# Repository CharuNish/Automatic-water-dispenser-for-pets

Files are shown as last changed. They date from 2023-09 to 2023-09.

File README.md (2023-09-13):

# Automatic-water-dispenser-for-pets
In the modern world, pet owners often face challenges in providing constant care and attention to 
their beloved companions due to their busy lifestyles. A significant issue arises when it comes to 
ensuring a continuous supply of clean water for pets, particularly during prolonged absences. To 
address this concern, we present a groundbreaking solution: an Automatic Water Dispenser for 
Pets. This innovative device is designed to detect the presence of pets and dispense water on 
demand, ensuring they have access to fresh water whenever they need it. 

## Design Process
### Determining features
To full fill the identified requirements following features were incoparated.
- Automatic detection of the presence of the animal with precision.
- Monitoring water level within the container
- Buzzer Alert System to alert the pet owner.

### Block Diagram
<p align="center">
  
</p>

### Functionality
The functionality process of the product is as follows:
- **Water level sensing:** The water level sensor continuously monitors the water level within the main reservoir. When the water level drops to a low point, the system activates a buzzer, promptly alerting the pet owner to refill the main reservoir, ensuring that the dispenser is always ready to meet the needs of the pets.
- **Dispensing Water:** Upon refilling the main reservoir with sufficient water, the buzzer deactivates, signaling that the dispenser is ready for use. When the ultra-sonic sensor detects the presence of an animal, such as a pet, the system triggers the microcontroller to activate the motor. 
- **Water Pumping:** The motor activates the water pump, facilitating the flow of water to the drinking plate positioned above. Pets can access a steady stream of clean water, promoting their wellbeing and ensuring they have access to fresh water whenever they need it.
- **Intelligent Water Recycling:** As the pet leaves the drinking area, any remaining water on the plate flows back into the dispenser through a filtration process. The filtration system efficiently cleans and purifies the water, removing impurities and contaminants, making it safe for future consumption.
- **Return to Main Reservoir:** Filtered water then returns to the main reservoir, where it is stored and ready for the next use. This process ensures that water is conserved and utilized responsibly, addressing concerns of water wastage and promoting sustainable pet care practices. 

### Component Selection
- **Atmega328P Microcontroller:** The Atmega328P serves as the brain of the system, controlling and coordinating the various components
- **HC-SR04 Ultrasonic Sensor:** The HC-SR04 ultrasonic sensor detects the presence of animals in proximity to the dispenser. The ultrasonic transmitter and receiver detect the presence of an object 2cm to 400cm away. Its ultrasonic transmitter produces 40kHz signal and the receiver collects the reflected signal if the object is within range.
- **SEN18 Water Level Sensor:** This sensor has ten exposed conducting tracks, of which five alternate strips are power tracks and the other five are sensing tracks. When the sensor is submerged in water (vertically), bridges are created between the five pairs of power and sensing tracks due to water’s conductivity. Thus, the sensor works like a variable resistor whose value at the sensing pin changes with the change in water level. The value is high when the water level is high and low when water level is low. The sensor can be powered with 3.3V or 5V on-board DC supply. The SEN18 water level sensor is crucial for monitoring the water level in the main reservoir. It enables the system to detect when the water level is low, triggering an alert for the owner to refill the reservoir.
- **5V Relay Module:** The 5V relay module acts as a switch to control the 12V submersible water pump. It allows the microcontroller to activate and deactivate the pump efficiently, controlling the flow of water to the drinking plate.
- **12V/2A Power Adapter:** The 12V/2A power adapter converts AC 230V to DC 12V and supplies the necessary power to the system, ensuring smooth and reliable operation of all components.
- **12V Submersible Water Pump:** The 12V submersible water pump is responsible for pumping water from the main reservoir to the drinking plate when activated by the microcontroller. Its submersible design ensures efficient water transfer while maintaining a tidy appearance.

### Schematic Design

<p align="center">
  
</p>

### BoM
  
| Component | Quantity |
| --- | ---|
|5V Relay Module  | 1 |
|12V Submergible water pump  | 1 |
|ATMega328P Microcontroller  | 1 |
|HC-SR04 Ultrasonic Sensor | 1 |
|SEN18 Water level sensor |	1 |
|12V Power Adapter | 1 |
|0.1µF Capacitor | 1 |
|0.33µF Capacitor |	1 |
|22pF Capacitor | 2 |
|L7805 Voltage regulator | 1 |
|16MHz Crystal Oscillator  |	1 |
|10kΩ resistor |	1 |
|Buzzer 	| 3 |
|JST Connectors (2port) |	2|
|JST Connectors (3port) |	1|
|JST Connectors (4port) |	1|
|JST Connectors (5port) |	1|

### PCB Design
Printed circuit board was designed with Altium Designer 23.3.1. It was a two-layer design. Manufacturing was done at JLCPCB in China. 

<p align="center">
  
</p>

#### Top Layer
<p align="center">

</p>

#### Bottom Layer
<p align="center">

</p>

### Enclosure Design
Enclosure design was designed with SOLIDWORKS 2020.enclosure consists of plate, sink and container. Plastic is used in the enclosure. 3mmx 5mm screws were used to connect parts. 

<div style="display: flex;">
  
  
</div>

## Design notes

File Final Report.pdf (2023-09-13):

## Department of Electronic and Telecommunication Engineering

## University of Moratuwa

## Semester 4 – Intake 2020

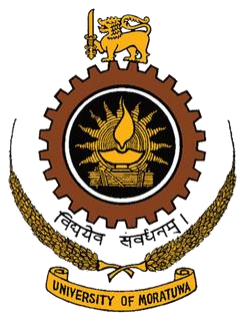
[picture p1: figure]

## Development of an Automatic Water Dispenser for pets

## Final Report

## H.M.C.N.K. Bandara

200063X

This document is submitted as a partial fulfilment of module EN2160 - Electronic Design Realization

July 25, 2023

## Table of Contents

## Abstract

In the modern world, pet owners often face challenges in providing constant care and attention to their beloved companions due to their busy lifestyles. A significant issue arises when it comes to ensuring a continuous supply of clean water for pets, particularly during prolonged absences. To address this concern, we present a groundbreaking solution: an Automatic Water Dispenser for Pets. This innovative device is designed to detect the presence of pets and dispense water on demand, ensuring they have access to fresh water whenever they need it. The dispenser's advanced filtration system guarantees that the water remains clean and safe for consumption, while any unused water is efficiently redirected back to the main reservoir for recycling. Furthermore, the system is equipped with alerts, promptly notifying pet owners to refill the water container when it becomes depleted. Thus, the objective of this report is to present a comprehensive solution that offers long-lasting access to clean water for pets, while promoting energy efficiency, cost-effectiveness, and accessibility to cater to the needs of both individual and institutional pet care scenarios.

## 1. Problem Definition

### 1.1. Introduction to the problem

The significance of pets in people's lives remains undeniably profound, yet the demands of contemporary busy schedules have left pet owners overwhelmed, leading to a concerning neglect of their pets' wellbeing. Furthermore, in a world where individuals often live in solitude, the desire for companionship drives a growing interest in adopting pets. However, potential pet adopters are frequently discouraged by the substantial costs and time commitment required for proper pet care.

In the absence of pet owners for extended periods, the conventional method of providing water through bowls proves inadequate, as pets are left to drink stagnant and potentially contaminated water for days or face dehydration due to insufficient water supply. The challenge extends beyond individual pet owners, with institutions like animal shelters, pet shops, and veterinary clinics struggling to ensure timely access to clean water for many animals in their care.

Though water fountains exist in the market, their reliance on continuous electricity raises concerns about sustainability and affordability. To address these multifaceted challenges, a pressing need arises for an innovative solution capable of providing pets with a constant supply of clean water for extended periods without depleting vital resources or imposing significant financial burdens on pet owners and institutions alike.

### 1.2. Need Analysis

The need analysis for the Automatic Water Dispenser for Pets, based on discussions and interviews with key stakeholders including pet owners, veterinarians, and pet shop owners, revealed the following essential requirements:

- Convenience for Busy Pet Owners: With modern lifestyles becoming increasingly hectic, pet owners are in dire need of a solution that alleviates the burden of constantly providing fresh water to their pets. The Automatic Water Dispenser offers a seamless and automated water supply, catering to the needs of busy pet owners who may be absent for extended periods.
- Enhanced Pet Wellbeing: The wellbeing of pets is a primary concern for all stakeholders. Ensuring access to clean and uncontaminated water is essential for maintaining the health and vitality of pets. The dispenser's filtration system, which purifies and recirculates water, guarantees that pets can always drink safe and fresh water.
- Addressing Loneliness: In an era where individuals often experience loneliness due to living alone, pets serve as valuable companions. The Automatic Water Dispenser supports this aspect by facilitating pet adoption, offering a solution for potential pet owners who seek companionship but are hesitant due to the time and effort required for pet care.

- Efficiency for Institutional Pet Care: Stakeholders involved in managing animal shelters, pet shops, and veterinary clinics face the challenge of providing water to a large number of animals. The Automatic Water Dispenser addresses this need by offering a consistent and efficient water supply system for institutional pet care settings.
- Sustainability and Energy Conservation: In the pursuit of a greener and more sustainable approach, stakeholders expressed the importance of an energy-efficient solution. The dispenser's ability to minimize electricity consumption and conserve water through recycling aligns with this critical need.
- Affordability and Accessibility: Stakeholders emphasized the significance of an affordable solution that is accessible to a wide range of customers. Cost-effective implementation of the Automatic Water Dispenser allows for broader adoption and benefits both individual pet owners and institutional users.
- User-Friendly Interface and Maintenance: A user-friendly design, simple installation, and easy maintenance were identified as essential attributes for the success of the product. Stakeholders highlighted the importance of clear instructions and guides to ensure seamless usage and upkeep of the dispenser.
- Real-Time Alerts and Monitoring: The need for timely alerts to refill the water container when it runs low was emphasized. Real-time monitoring and notifications enable pet owners and institutional caregivers to address water supply needs promptly, ensuring pets' continuous access to water.

In conclusion, the need analysis indicates that the Automatic Water Dispenser for Pets effectively addresses the pressing concerns of key stakeholders. By offering convenience, improved pet wellbeing, and sustainability, the product presents a comprehensive solution that aligns with the interests and requirements of pet owners, veterinarians, and pet shop owners alike.

## 2. Market Goals

- Competitive Pricing and Affordability: Offer competitive price of Rs.20 000 that ensures the product's accessibility to a broad customer base, appealing to both price-conscious individual pet owners and budget-conscious institutional buyers.
- Penetration and Adoption: The primary market goal is to achieve widespread penetration and adoption of the Automatic Water Dispenser in the pet care market, targeting both individual pet owners and institutional customers, such as animal shelters, pet shops, and veterinary clinics.
- Market Leadership: Establish the product as a market leader by offering a superior and innovative solution that outperforms existing water dispensing options, positioning it as the go-to choice for pet owners and caregivers seeking an automated, energy-efficient, and cost-effective solution.
- Brand Awareness and Trust: Build strong brand awareness and trust among potential customers through effective marketing strategies, testimonials, and positive reviews, highlighting the product's benefits and reliability.
- Market Expansion: Explore opportunities for market expansion by targeting new geographical regions and demographics, recognizing the growing global demand for pet care solutions, especially in urban areas with busy pet owners.
- Customer Satisfaction and Retention: Focus on customer satisfaction by continuously improving the product's functionality, durability, and user experience, leading to increased customer retention and loyalty.
- Partnerships and Distribution Channels: Forge strategic partnerships with pet supply stores, veterinarians, and online retailers to expand the product's distribution channels, making it readily available to potential customers.
- Regulatory Compliance: Ensure the product complies with all relevant safety and environmental regulations, obtaining necessary certifications to instill confidence in customers and regulatory bodies.
- Sustainable Growth and Profitability: Achieve sustainable growth and profitability in the market, balancing product quality, cost-effectiveness, and scalability to create a strong foundation for the company's long-term success.

- Customer Education: Emphasize the importance of the Automatic Water Dispenser's features, benefits, and environmental impact through educational content, tutorials, and guides to empower customers to make informed purchasing decisions.

By pursuing these market goals, the Automatic Water Dispenser for Pets aims to become a leading and trusted solution in the pet care industry, meeting the needs of both pet owners and institutional customers while promoting responsible and sustainable pet care practices.

## 3. Design Process

### 3.1. Determining the features

To address the requirements outlined in the need list, the following components and design considerations are proposed:

- Ultra Sonic Sensor: The Automatic Water Dispenser for Pets incorporates an advanced Ultra Sonic Sensor, enabling the product to detect the presence of the animal with precision. This feature directly addresses the need for convenience for busy pet owners, ensuring that water is dispensed only when the pet is present, eliminating unnecessary water wastage and optimizing the dispenser's efficiency.
- Water Level Sensor: With its integrated Water Level Sensor, the dispenser intelligently monitors the water level within the container. This crucial feature fulfills the need for enhanced pet wellbeing, as it prevents pets from drinking contaminated water or facing dehydration by alerting pet owners when the water level is low. Additionally, for institutional settings, the sensor helps manage water supply efficiently, benefiting pet shops, vet clinics, and animal shelters, where the proper care of numerous animals is essential.
- Buzzer Alert System: To meet the requirement of real-time alerts and monitoring, the Automatic Water Dispenser is equipped with a Buzzer Alert System. When the water level reaches a critical point, the buzzer promptly notifies pet owners to refill the container. This not only ensures that pets always have access to fresh water, but also addresses the need for sustainability, as it minimizes water wastage and helps pet owners conserve resources responsibly.

### 3.2. Block Diagram

The proposed block diagram outlines the system’s functionality and critical components.

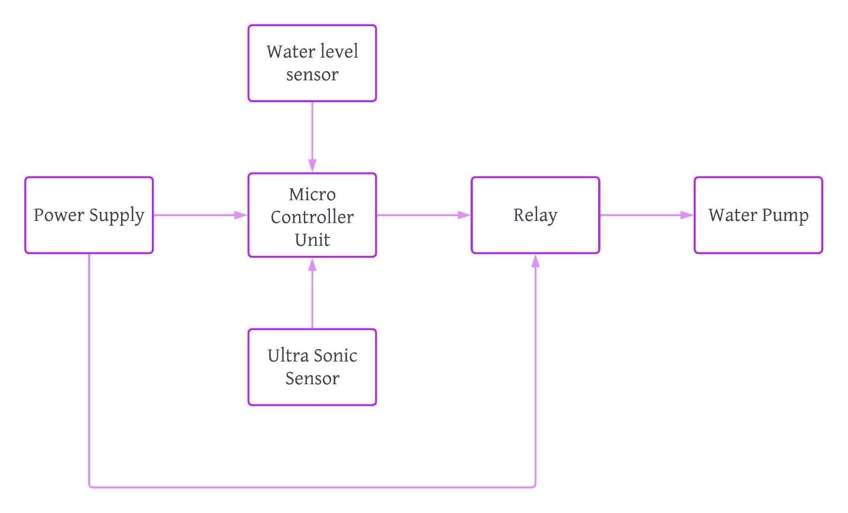
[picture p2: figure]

### 3.3. Functionality

The functionality process of the product is as follows:

- Water Level Sensing:
The water level sensor continuously monitors the water level within the main reservoir. When the water level drops to a low point, the system activates a buzzer, promptly alerting the pet owner to refill the main reservoir, ensuring that the dispenser is always ready to meet the needs of the pets.
- Dispensing Water:
Upon refilling the main reservoir with sufficient water, the buzzer deactivates, signaling that the dispenser is ready for use. When the ultra-sonic sensor detects the presence of an animal, such as a pet, the system triggers the microcontroller to activate the motor.
- Water Pumping:
The motor activates the water pump, facilitating the flow of water to the drinking plate positioned above. Pets can access a steady stream of clean water, promoting their wellbeing and ensuring they have access to fresh water whenever they need it.

- Intelligent Water Recycling:
As the pet leaves the drinking area, any remaining water on the plate flows back into the dispenser through a filtration process. The filtration system efficiently cleans and purifies the water, removing impurities and contaminants, making it safe for future consumption.
- Return to Main Reservoir:
Filtered water then returns to the main reservoir, where it is stored and ready for the next use. This process ensures that water is conserved and utilized responsibly, addressing concerns of water wastage and promoting sustainable pet care practices.

## 4. Implementation

### 4.1. Components Selection

Selected Components for Successful Implementation of the Automatic Water Dispenser for Pets:

1. Atmega328P Microcontroller: The Atmega328P serves as the brain of the system, controlling and coordinating the various components. It is connected to water-level sensor and ultrasonic sensor, which detect water level and pet’s presence near the water bowl, respectively. When ultrasonic sensor detects presence of the pet nearby, it provides a signal to Atmega328P. The Atmega328P program compares the received signal with the programmed value and gives signal to its digital output to operate (energize) relay if the programmed conditions are fulfilled. Otherwise, the relay remains de-energized. Data Sheet (https://www.alldatasheet.com/view.jsp?Searchword=ATMEGA328P&sField=4)
2. HC-SR04 Ultrasonic Sensor: The HC-SR04 ultrasonic sensor detects the presence of animals in proximity to the dispenser. The ultrasonic transmitter and receiver detect the presence of an object 2cm to 400cm away. Its ultrasonic transmitter produces 40kHz signal and the receiver collects the reflected signal if the object is within range. Data Sheet (https://www.electroschematics.com/hc-sr04-datasheet/)
3. SEN18 Water Level Sensor: This sensor has ten exposed conducting tracks, of which five alternate strips are power tracks and the other five are sensing tracks. When the sensor is submerged in water (vertically), bridges are created between the five pairs of power and sensing tracks due to water’s conductivity. Thus, the sensor works like a variable resistor whose value at the sensing pin changes with the change in water level. The value is high when the water level is high and low when water level is low. The sensor can be powered with 3.3V or 5V on-board DC supply. The SEN18 water level sensor is crucial for monitoring the water level in the main reservoir. It enables the system to detect when the water level is low, triggering an alert for the owner to refill the reservoir. User Manual (https://curtocircuito.com.br/datasheet/sensor/nivel_de_agua_analogico.pdf)
4. 5V Relay Module: The 5V relay module acts as a switch to control the 12V submersible water pump. It allows the microcontroller to activate and deactivate the pump efficiently, controlling the flow of water to the drinking plate. Data Sheet (https://components101.com/sites/default/files/component_datasheet/Relay-Module-Datasheet.pdf)

5. 12V/2A Power Adapter: The 12V/2A power adapter converts AC 230V to DC 12V and supplies the necessary power to the system, ensuring smooth and reliable operation of all components. It provides sufficient power for the microcontroller, sensors, relay module, and water pump.
6. 12V Submersible Water Pump: The 12V submersible water pump is responsible for pumping water from the main reservoir to the drinking plate when activated by the microcontroller. Its submersible design ensures efficient water transfer while maintaining a tidy appearance.

By integrating these selected components into the design and implementation of the Automatic Water Dispenser for Pets, the product is equipped with the necessary tools to detect pets' presence, manage water levels, and provide a continuous supply of clean water. The combination of the microcontroller, sensors, relay module, power adapter, and water pump create a comprehensive and efficient system that fulfills the product's intended functionalities and addresses the needs of both individual pet owners and institutional pet care providers.

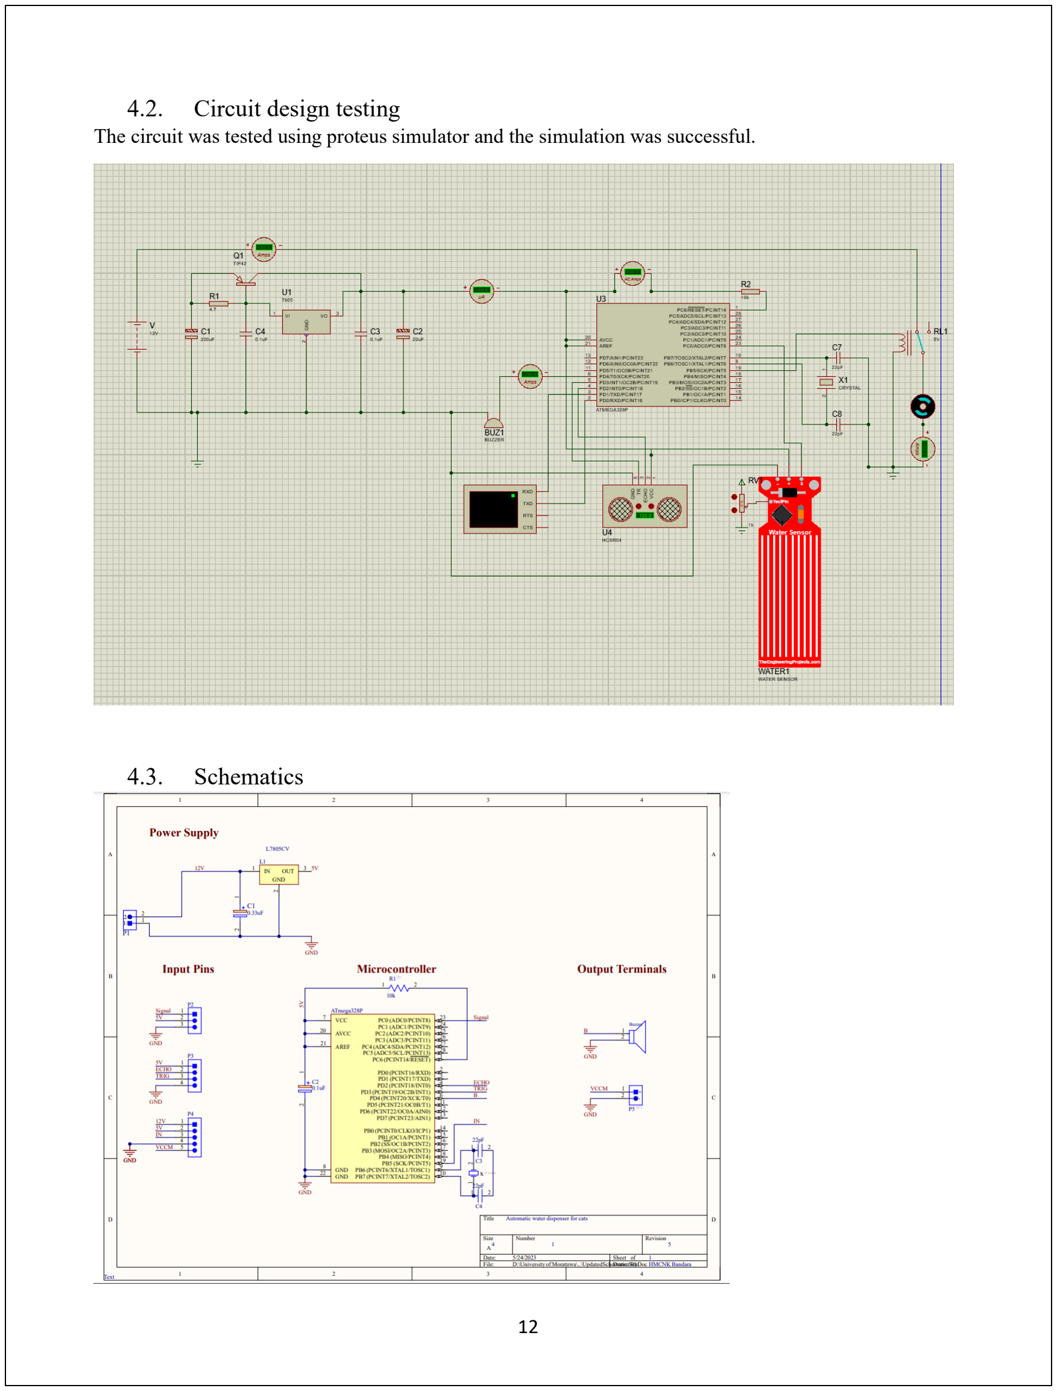
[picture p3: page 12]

### 4.2. Circuit design testing

The circuit was tested using proteus simulator and the simulation was successful.

### 4.3. Schematics

### 4.4. Printed Circuit Board Design

Printed circuit board was designed with Altium Designer 23.3.1. It was a two-layer design. Manufacturing was done at JLCPCB in China. Therefore, online available JLCPCB design rules were imported to Altium Designer.

Refer Appendix I for schematic diagram and layout respectively.

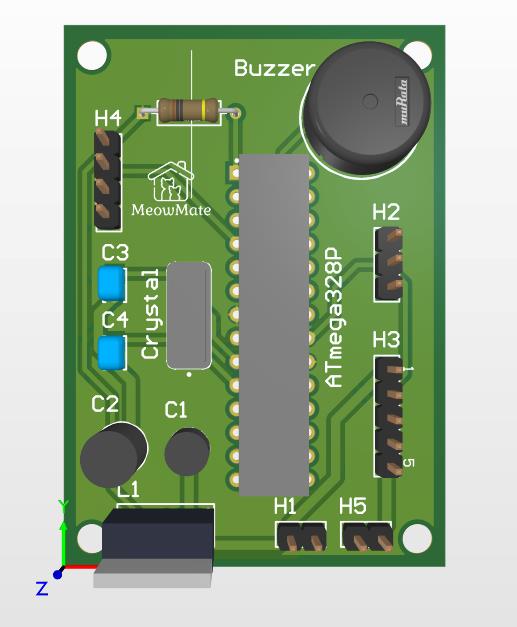
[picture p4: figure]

### 4.5. Enclosure Design

Enclosure design was designed with SOLIDWORKS 2020.enclosure consists of plate, sink and container. Plastic is used in the enclosure. 3mmx 5mm screws were used to connect parts.

### SOLIDWORKS Design

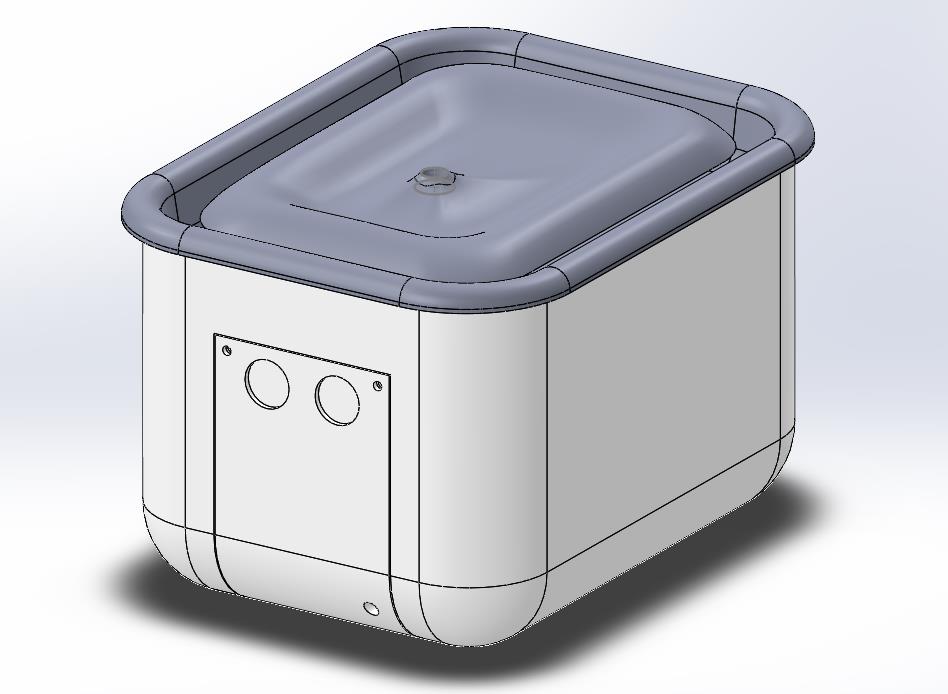
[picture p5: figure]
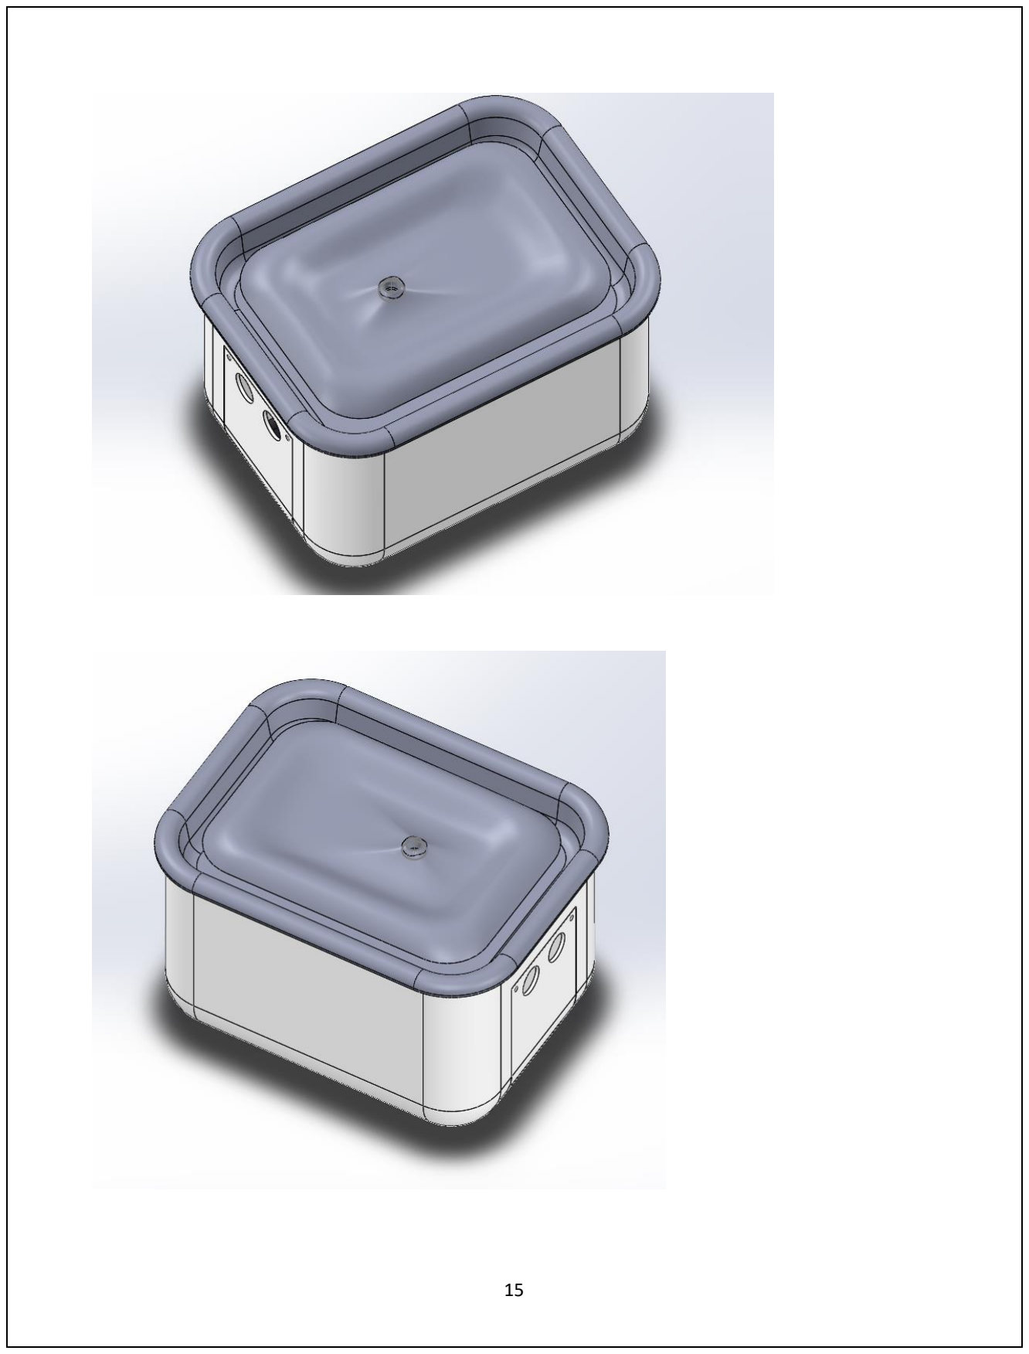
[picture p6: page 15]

## 5. BOM

Description | Quantity
5V Relay Module | 1
12V Submergible water pump | 1
ATMega328P Microcontroller | 1
HC-SR04 Ultrasonic Sensor | 1
SEN18 Water level sensor | 1
12V Power Adapter | 1
0.1µF Capacitor | 1
0.33µF Capacitor | 1
22pF Capacitor | 2
L7805 Voltage regulator | 1
16MHz Crystal Oscillator | 1
10kΩ resistor | 1
Buzzer | 1
JST Connectors (2port) | 2
JST Connectors (3port) | 1
JST Connectors (4port) | 1
JST Connectors (5port) | 1
Wires | 1m
PCB (Manufactured by JLC PCB) | 1
Enclosure | 1

## 6. Software implementation

### Calibration

#define sensorPin A0

int val = 0;

void setup()

{

Serial.begin(9600);

}

void loop() {

int level = readSensor();

delay(1000);

}

int readSensor() {

val = analogRead(sensorPin);

return val;

}

### Dispenser

int Threshold = 650;

#define sensorPin A0

#define echoPin 2

#define trigPin 3

#define Control 13

int val = 0;

long duration;

int distance;

void setup()

{

Serial.begin(9600);

pinMode(trigPin, OUTPUT);

pinMode(echoPin, INPUT);

pinMode(Control, OUTPUT);

digitalWrite(Control, LOW);

}

void loop()

{

digitalWrite(trigPin, LOW);

delayMicroseconds(2);

digitalWrite(trigPin, HIGH);

delayMicroseconds(10);

digitalWrite(trigPin, LOW);

duration = pulseIn(echoPin, HIGH);

distance = duration * 0.034 / 2;

int level = analogRead(A0);

if (distance > 30)

{

digitalWrite(Control,LOW);

}

else

{

if (level > Threshold)

{

digitalWrite(Control, LOW);

}

else

{

digitalWrite(Control, HIGH);

}

delay(100);

}

}

## 7. Future Developments

In the pursuit of future developments for the Automatic Water Dispenser for Pets, the following innovative approaches can be explored:

- Smart Connectivity: Incorporate Wi-Fi or Bluetooth connectivity to allow pet owners to remotely monitor and control the dispenser through a dedicated mobile app. This feature enables real-time alerts, water level monitoring, and convenient dispenser activation, even when the owners are away from home.
- Pet Recognition and Personalization: Implement advanced sensors and machine learning algorithms to recognize and differentiate between multiple pets. This technology would allow for personalized water dispensing settings based on each pet's preferences and needs, ensuring optimal hydration for every individual.
- Enhanced Filtration System: Upgrade the filtration system to include additional stages, such as activated carbon or UV purification, to further enhance water quality. This improvement would effectively remove a broader range of contaminants, ensuring the cleanest and safest drinking water for pets.
- Advanced Water Level Monitoring: Introduce an advanced water level monitoring system that provides historical data and usage patterns. This valuable information can be used to analyze pets' drinking habits, detect any irregularities, and optimize water usage for improved efficiency.
- Variable Reservoir Capacities: Offer a range of main reservoir capacities to cater to the diverse needs of pet owners, accommodating single-pet households as well as multi-pet environments. This flexibility ensures that the dispenser can be tailored to individual requirements.
- Food Dispensing Integration: Explore the possibility of integrating a food dispensing system alongside the water dispenser. This innovation would enable pet owners to automate feeding routines, enhancing convenience and promoting a balanced diet for their pets.
- Medicine Dispensing Capability: Add a system that allows for the precise addition of medicine to the water for individual pets. This feature would aid in administering medications to pets, particularly useful for those with specific health conditions or in need of regular supplements.

By incorporating these innovative approaches into the Automatic Water Dispenser for Pets, the product can truly revolutionize the way pet owners care for their beloved companions. With smart connectivity, personalized pet care, advanced filtration, and additional functionalities like food and medicine dispensing, the dispenser becomes a comprehensive and intelligent solution for pet health and wellbeing.

## 8. Appendix

### Appendix I – PCB

### Schematic

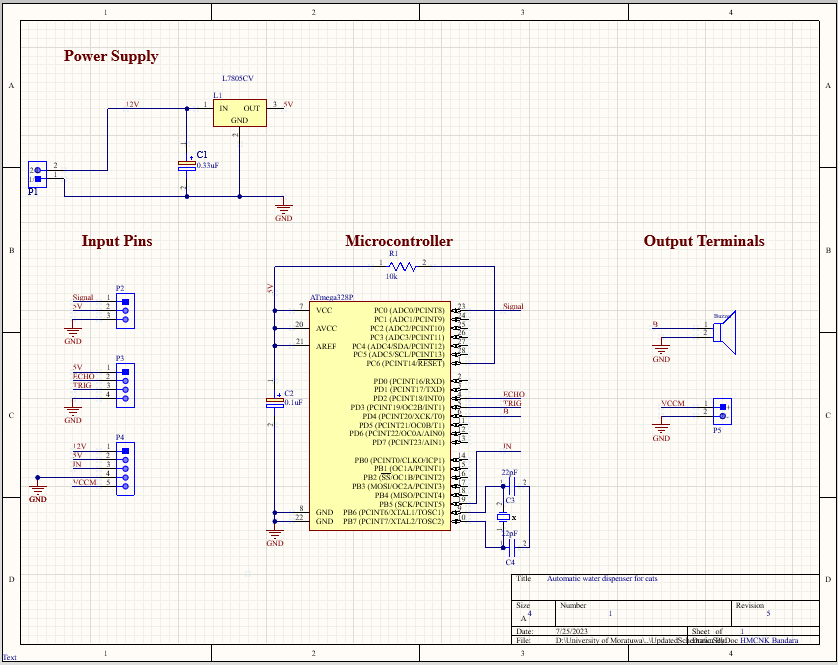
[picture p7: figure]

### 2D - Top Layer

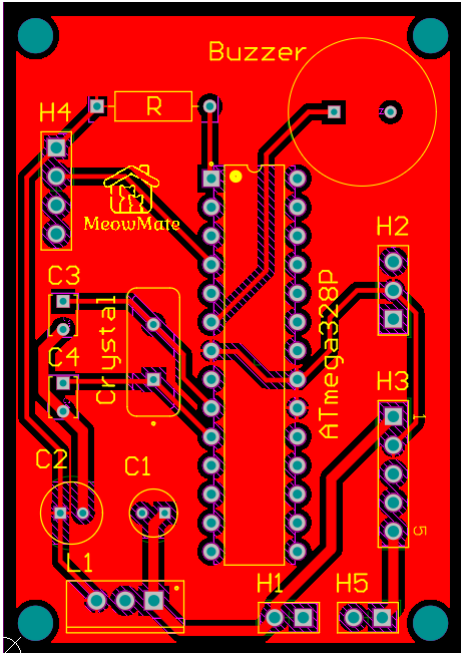
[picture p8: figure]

### 2D - Bottom Layer

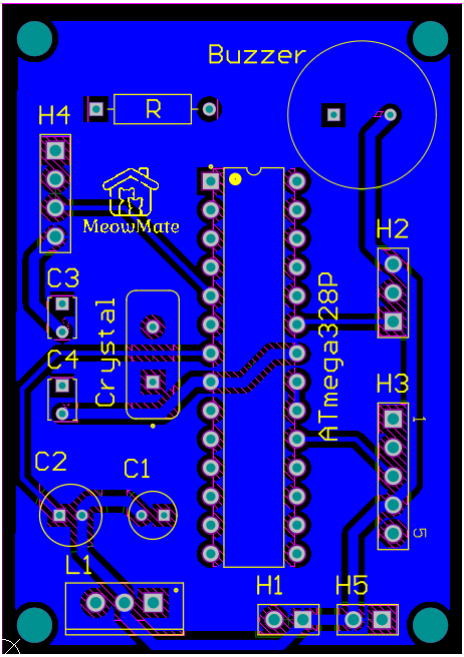
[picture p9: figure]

### Board Planning mode

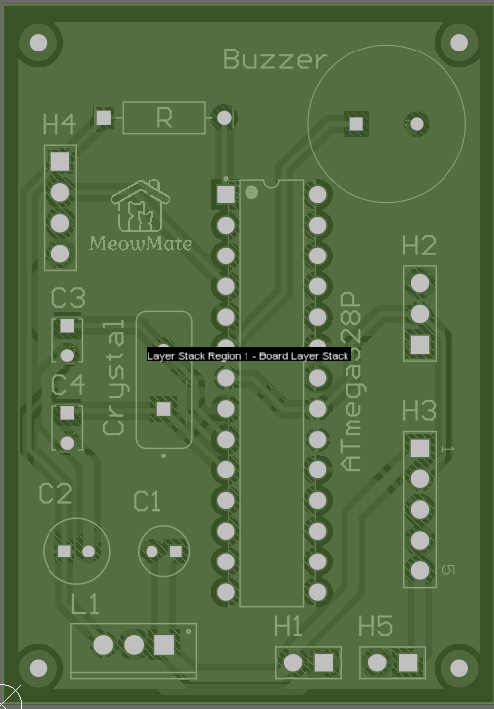
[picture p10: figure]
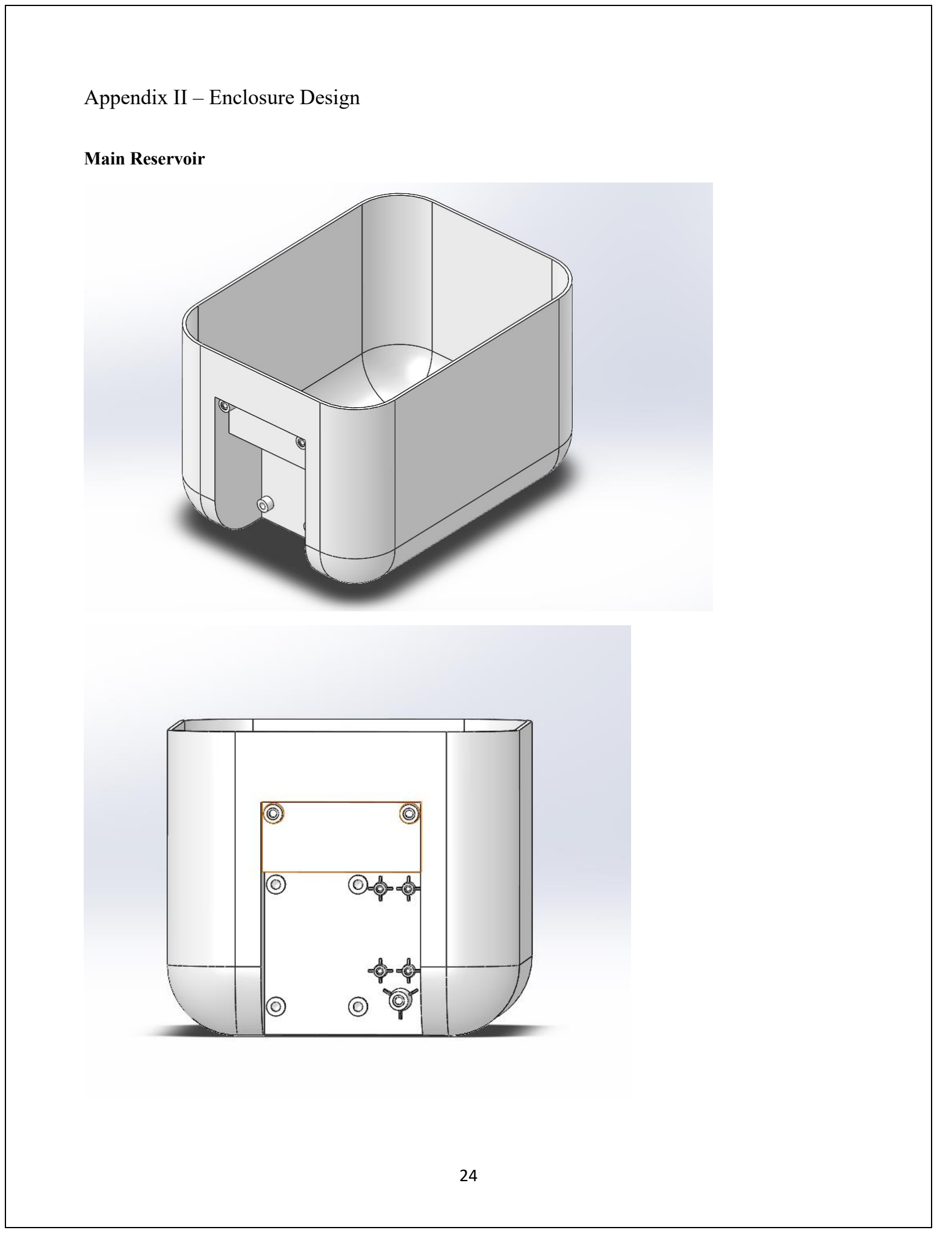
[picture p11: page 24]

### Appendix II – Enclosure Design

Main Reservoir

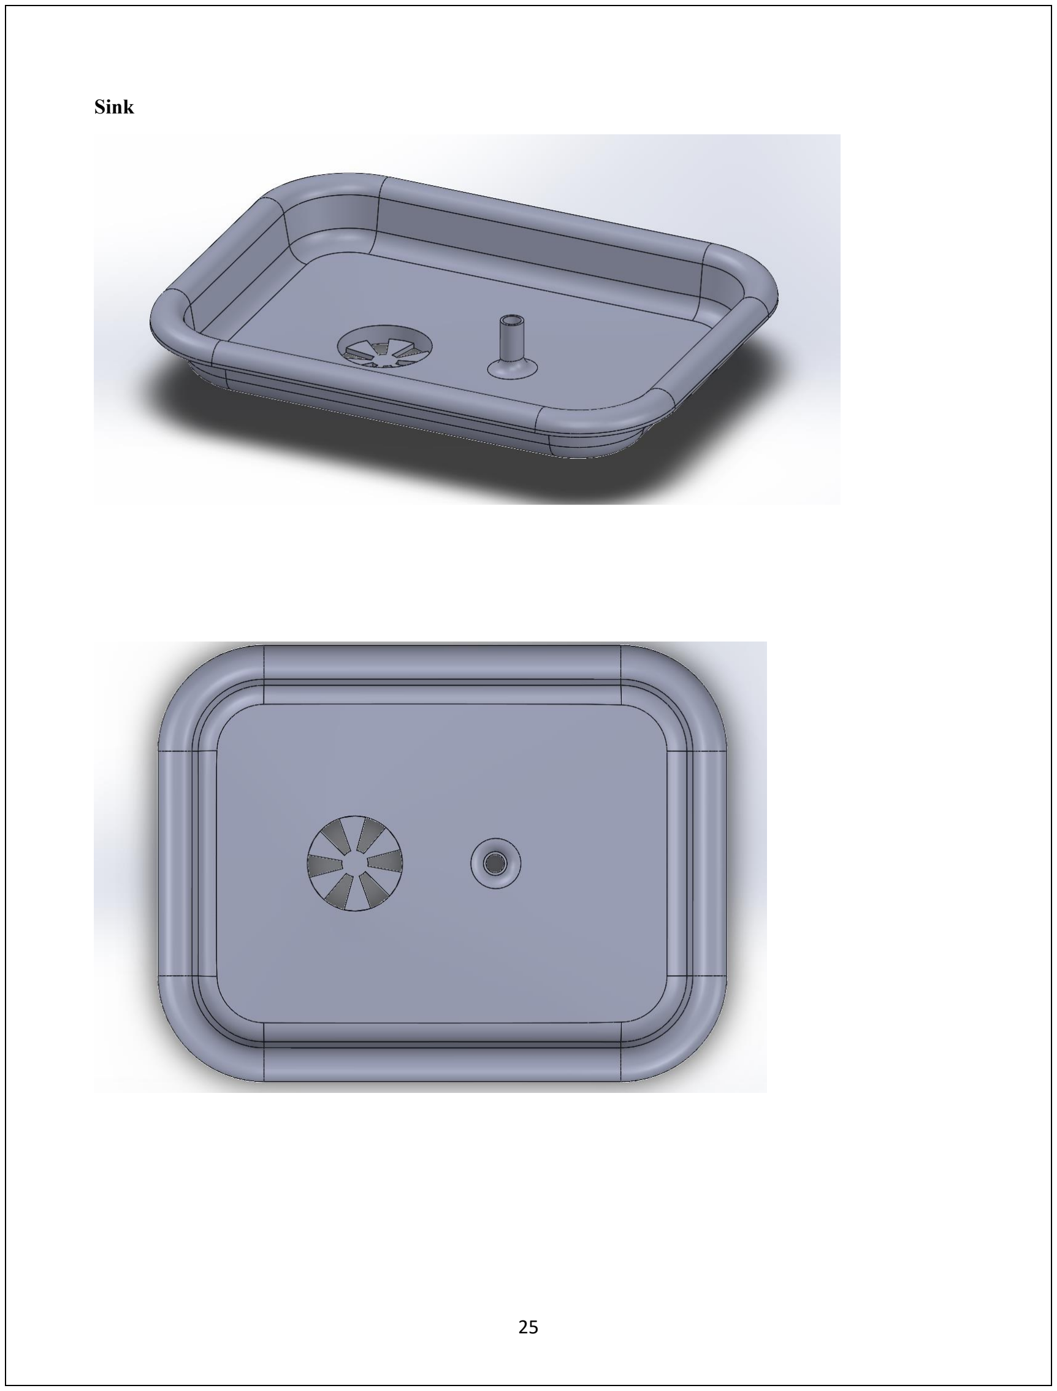
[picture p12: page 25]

Sink

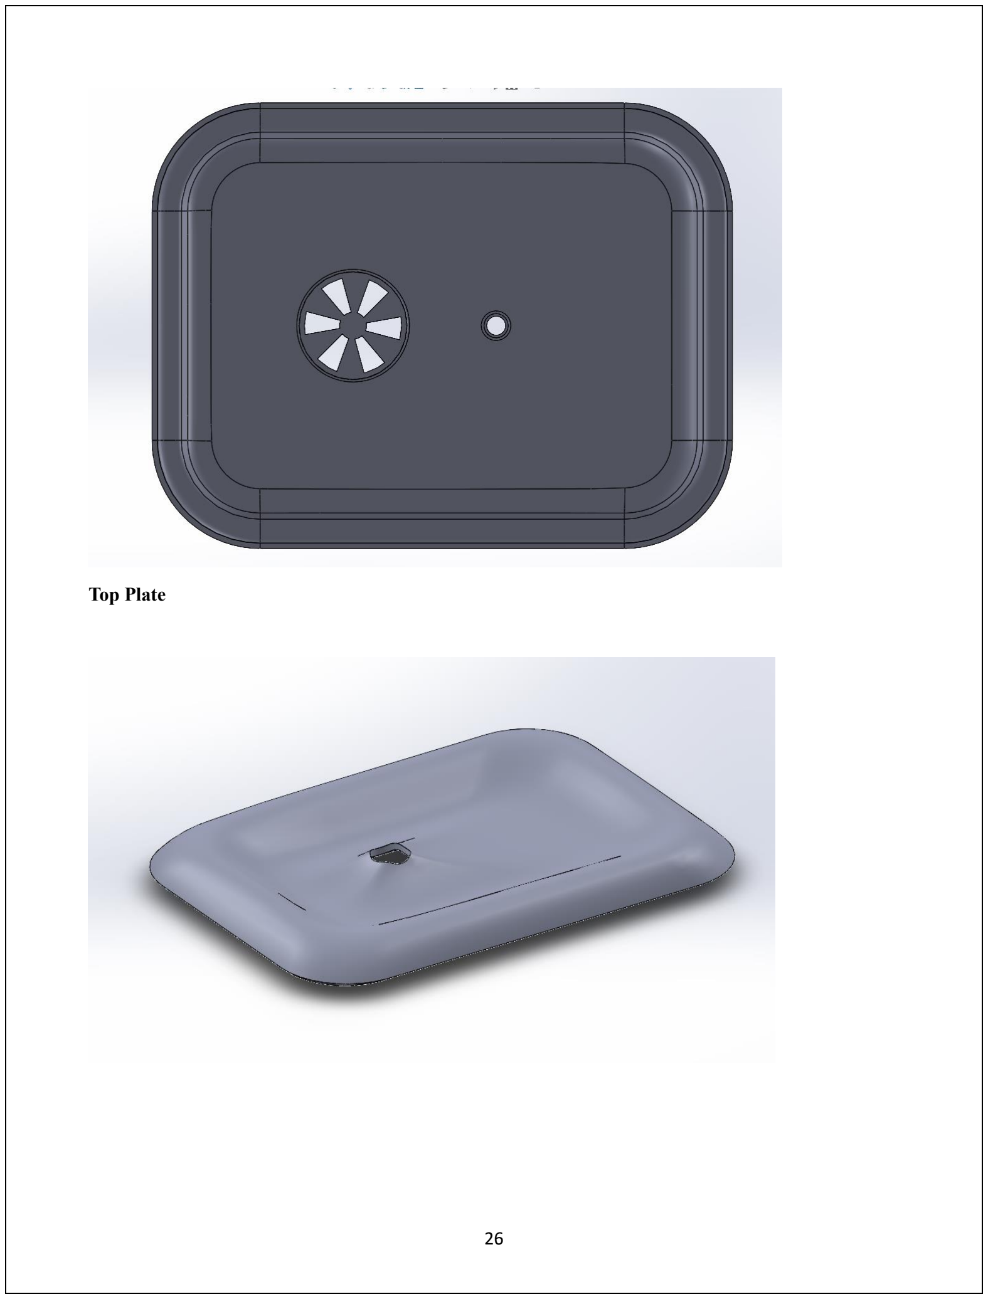
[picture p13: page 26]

Top Plate

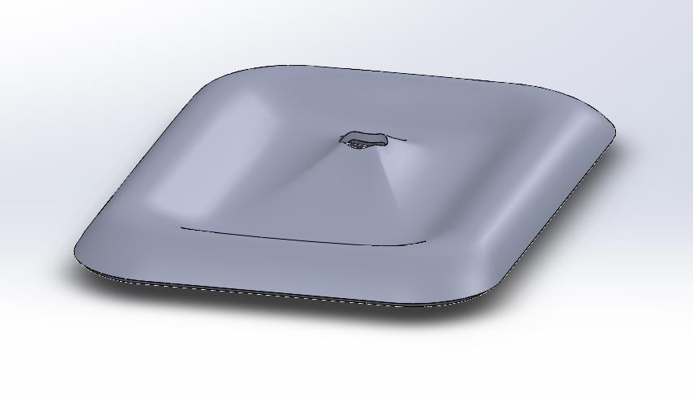
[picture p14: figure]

### Appendix 3 – User Manual

User Manual – Automatic water dispenser for pets

Introduction

Thank you for choosing our Automatic Water Dispenser for Pets. This user manual aims to provide you with all the necessary information to ensure a seamless and safe experience while using our product. The dispenser is designed to provide a constant supply of clean water for your pets, even when you are away, promoting their wellbeing and health.

Product Overview

The Automatic Water Dispenser for Pets is an innovative device that automatically detects your pet's presence and dispenses water on demand. Equipped with an ultra-sonic sensor and water level sensor, the dispenser ensures efficient water usage and filtration for your pet's convenience. The smart design allows for water recycling, making it an energy-efficient and eco-friendly solution.

Key Features

- Ultra-sonic Sensor: Detects your pet's presence, activating the water dispensing mechanism when needed.
- Water Level Sensor: Monitors the water level in the main reservoir and alerts you when it's time to refill.
- Buzzer Alert System: Notifies you when the water level is low and requires refilling.
- Energy-efficient: The dispenser conserves water through intelligent recycling and minimizes electricity consumption.
- Filtration System: Ensures clean and safe water for your pets by removing impurities and contaminants.
- User-friendly Interface: Simple controls make it easy to set up and operate the dispenser.

Safety Precautions

- Use only the provided power adapter and specified accessories to avoid damage or hazards.
- Do not immerse the main unit in water to prevent electrical hazards.
- Regularly check the power cord for signs of damage and ensure its kept away from sharp objects or pet bites.

Assembling

1. Unbox the Automatic Water Dispenser for Pets and ensure all components are included.
2. Attach the water pump securely to the main container's designated compartment.
3. Place the filtration system in the filter compartment in the sink.
4. Connect the power adapter to the dispenser and the electrical outlet.
5. Wait for the buzzer sound to confirm proper setup.

Maintenance

- Regularly check and clean the water pump and filtration system to ensure optimal performance.
- Refill the main reservoir as needed, guided by the water level sensor and buzzer alerts.
- If the dispenser exhibits any unusual behavior or malfunctions, refer to the troubleshooting section of this manual or contact our customer support for assistance.

Troubleshooting

1. Water Dispenser Not Activating
- Check if the power adapter is securely connected to the dispenser and the electrical outlet.
- Ensure that the power switch is turned on.
- Verify that the water level is sufficient for the dispenser to activate.
2. No Water Flowing to the Drinking Plate
- Check if the water pump is securely connected to the dispenser and the power supply.
- Inspect the water pump for any clogs or obstructions that may be blocking the water flow.
- Ensure that the water level is above the minimum requirement for the pump to function properly.
3. Buzzer Continuously Activated
- Check the water level in the main reservoir. Refill the reservoir if the water level is low.
- Inspect the water level sensor for any debris or malfunctions that may be triggering the alert.
- Ensure that the water level sensor is securely connected to the dispenser.
4. Water Leakage from the Dispenser
- Check for any cracks or damage in the dispenser's exterior that may be causing the leakage.
- Verify that all connections, especially those related to the water pump and filtration system, are tightly sealed.
- Ensure that the dispenser is placed on a level surface to prevent water from spilling.
5. Unusual Noises During Operation
- Check for any loose components or parts within the dispenser.
- Inspect the water pump for any foreign objects that may be causing the noise.
- If the noise persists, contact our customer support for further assistance.
6. Inaccurate Sensor Detection
- Clean the sensors and PCB carefully to remove any dirt or debris that might be affecting their functionality.
- Ensure that there are no obstacles or obstructions in the sensor's detection area.
- If the issue persists, consider recalibrating the sensors or contact our customer support for guidance.
7. Dispenser Not Powering On
- Check the power adapter and electrical outlet for any issues. Try using a different outlet.
- If the power adapter appears damaged or faulty, replace it with a compatible one.
- Inspect the power switch and make sure it is functioning correctly.

Safety Information and Warnings

- Do not attempt to disassemble or repair the dispenser yourself. Contact authorized service personnel for any repairs.
- Avoid exposing the dispenser to extreme temperatures or direct sunlight.
- Always unplug the dispenser from the power outlet before cleaning or performing any maintenance.
- If the dispenser or power cord is damaged, discontinue use immediately and seek professional assistance.

We hope this user manual helps you make the most of your Automatic Water Dispenser for Pets. For any further inquiries or assistance, feel free to contact our customer support team.

Note: The contents of this user manual are subject to change without notice due to ongoing product improvements. Please refer to the latest version available on our website for the most up-to-date information.

### Appendix 4 - Maintenance Manual

Maintenance Manual – Automatic water dispenser for pets

Introduction

Welcome to the Maintenance Manual for the Automatic Water Dispenser for Pets. Regular maintenance is essential to ensure the longevity and optimal performance of your product. This manual provides step-by-step instructions for cleaning, troubleshooting, and handling of the dispenser, ensuring a safe and seamless experience for you and your pets.

Maintenance Schedule

Regular inspections and cleaning are vital to keep the Automatic Water Dispenser functioning efficiently. Here's a suggested maintenance schedule:

1. Daily: Check water level and refill as needed. Inspect the product's exterior for any spills or debris.
2. Weekly: Clean the product's exterior, sensors, and PCB to prevent dust buildup and maintain hygiene.
3. Monthly: Perform a thorough inspection of the water pump, filtration system, and all connections for any signs of wear or damage.

Cleaning Procedures

1. Product Exterior:
- Wipe the exterior with a soft, damp cloth to remove dust and dirt.
- Use a mild detergent if needed but avoid harsh chemicals that may damage the surface.
2. Product Interior and Filtration System:
- Turn off the power and unplug the dispenser before cleaning the interior.
- Carefully remove the filtration system and wash it under running water.
- Allow all components to air-dry completely before reassembling.
3. Sensors and PCB:
- Gently wipe the sensors and PCB with a dry, lint-free cloth to remove any dirt or moisture.
- Avoid using water or cleaning agents on the sensors to prevent damage.

Troubleshooting

If the Automatic Water Dispenser exhibits any issues, refer to the Troubleshooting section in the User Manual. Common issues and potential solutions will be outlined there. If problems persist, please contact our customer support for further assistance.

Replacement Parts

In case of damaged or malfunctioning components, contact our authorized service centers to purchase genuine replacement parts. Only use original parts to maintain the product's integrity and performance.

Warranty Information

Please refer to the Warranty Information provided in the product packaging or on our website for details regarding the product's warranty coverage and terms.

Safety Precautions

- Always unplug the dispenser before performing any maintenance or cleaning.
- Avoid exposing the dispenser to water or harsh cleaning agents to prevent electrical hazards.
- Do not disassemble the product beyond what is specified in this maintenance manual.

Storage and Transportation

- Store the Automatic Water Dispenser in a cool, dry place away from direct sunlight and extreme temperatures.
- When transporting the dispenser, secure it properly to prevent damage or shifting during transit.

Regular maintenance and proper care will ensure the continued functionality and longevity of your Automatic Water Dispenser for Pets. If you have any questions or concerns, please do not hesitate to reach out to our customer support team for assistance.

### Appendix 5 – Production Manual

Production Manual – Automatic water dispenser for pets

Introduction

Welcome to the Automatic Water Dispenser for Pets Production Manual. This comprehensive guide provides a detailed outline of the step-by-step procedures and best practices for manufacturing the Automatic Water Dispenser for Pets. It is crucial to carefully follow these instructions to ensure consistent and efficient production, resulting in high-quality products. Before commencing any manufacturing activities, please thoroughly familiarize yourself with the entire production process.

Bill of Materials

Description | Quantity
5V Relay Module | 1
12V Submergible water pump | 1
ATMega328P Microcontroller | 1
HC-SR04 Ultrasonic Sensor | 1
SEN18 Water level sensor | 1
12V Power Adapter | 1
0.1µF Capacitor | 1
0.33µF Capacitor | 1
22pF Capacitor | 2
L7805 Voltage regulator | 1
16MHz Crystal Oscillator | 1
10kΩ resistor | 1
Buzzer | 1
JST Connectors (2port) | 2
JST Connectors (3port) | 1
JST Connectors (4port) | 1
JST Connectors (5port) | 1
Wires | 1m
PCB (Manufactured by JLC PCB) | 1
Enclosure | 1

Production Process

PCB Fabrication

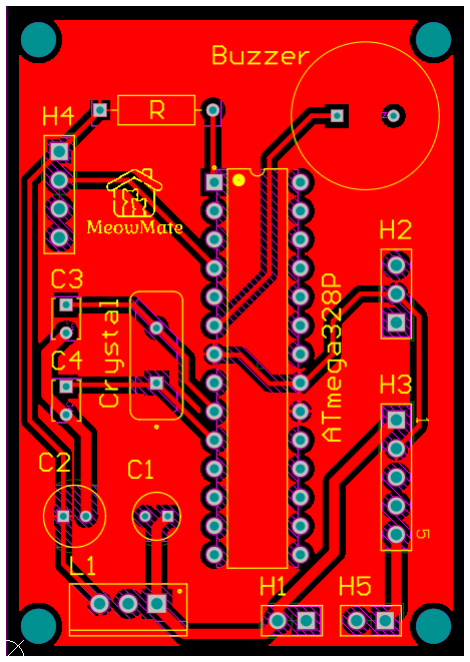
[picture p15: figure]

PCB Design and Layout

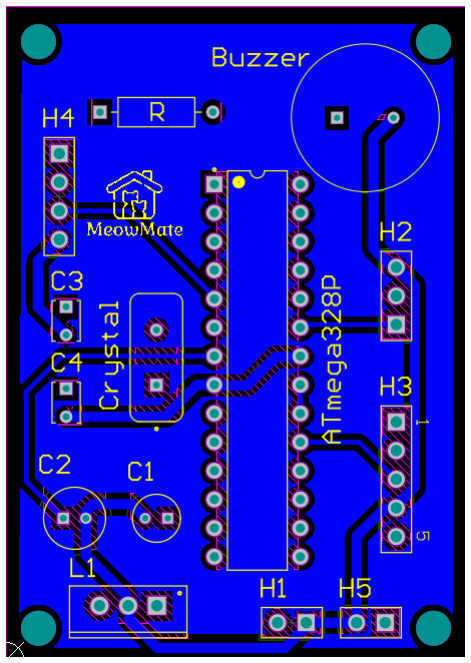
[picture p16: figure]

Create the PCB design using computer-aided design (CAD) software, ensuring the layout accommodates all the components and connections.

Consider proper grounding and routing to minimize interference and ensure signal integrity.

If you are using Altium Designer to design the schematic and the PCB following components can be used.

Description | Footprint Name | Designator
ATMega328P Microcontroller 8-bit AVR Microcontroller, 32KB Flash, 1KB EEPROM, 2KB SRAM, 28-pin PDIP, Industrial Grade (-40°C to 85°C) | 28P3 | ATMega328P
0.33µF Capacitor | CAPPRD200W45D425H650 | C1
0.1µF Capacitor | CAPPRD200W50D550H1200 | C2
22pF Capacitor Cap Ceramic 22pF 100V C0G ±5% Radial 2.5mm +125°C Bulk | FP-RCE0DB-MFG | C3, C4
L7805 Voltage regulator Positive Voltage Regulator, 5V, 3-Pin TO-220 | TO220 | L1

16MHz Crystal Oscillator Resistance Weld Thru-Hole Crystal, 16 MHz, -20 to 70 degC, 2-Pin THD, RoHS, Bulk | FOX-FOXSLF160-20 | Crystal
10kΩ resistor RES 10 OHM 1/4W 5% AXIAL | FP-CFR-25-MFG | R
Buzzer AUDIO PIEZO TRANSDUCER 30V TH | FP-PKM13EPYH4000-A0-MFG | Buzzer
2 Pin Header for the power supply and water pump Pin Header, pitch 2.54 mm, THT, Vertical, single row, 2p | 61300211121 | H1, H5
3 Pin Header for the water level sensor Pin Header, pitch 2.54 mm, THT, Vertical, single row, 3p | 61300211121 | H2
5 Pin Header for the relay module Pin Header, pitch 2.54 mm, THT, Vertical, single row, 5p | 61300211121 | H3
4 Pin Header for the ultra sonic sensor Pin Header, pitch 2.54 mm, THT, Vertical, single row, 4p | 61300211121 | H4

Prototype Testing

- Create a prototype of the PCB to validate the design and ensure its functionality.
- Thoroughly test the prototype for any issues or shortcomings.

Mass Production

- Once the prototype is successfully tested, proceed with mass production of the PCB.
- Collaborate with a reputable PCB manufacturing facility to maintain consistent quality.

Component Assembly

Component Procurement

- Source the necessary electronic components from authorized suppliers, adhering to quality standards and specifications.
- Ensure the availability of the Atmega328P microcontroller, water sensor, and ultrasonic sensor.

Soldering

- Assemble the electronic components on the PCB using precise soldering techniques, either automated or manual.
- Pay close attention to soldering to prevent loose connections and faulty joints.

Firmware Integration

Atmega328P Programming

- Develop and test the firmware code for the Atmega328P microcontroller, incorporating the water sensor and ultrasonic sensor functionalities.

Enclosure Selection

- Select a suitable enclosure that accommodates all components and provides adequate protection for the Automatic Water Dispenser.
- Ensure the enclosure meets necessary safety standards and environmental requirements.

Labeling and Branding

- Apply product labels and branding on the exterior of the enclosure as per the organization's guidelines.

Quality Control

Functional Testing

- Conduct thorough functional testing of each assembled Automatic Water Dispenser to verify accurate water level sensing and ultrasonic sensor detection.

Calibration

- Calibrate the water sensor and ultrasonic sensor to ensure precise measurements and reliable operation.

Buzzer Functionality

- Test the buzzer function to ensure it activates appropriately when the water level is low or when pets are detected.

Packaging and Shipping

Product Packaging

- Package each Automatic Water Dispenser securely to safeguard against damage during transportation and storage.
- Include user manuals and relevant documentation with each unit.

Shipping and Logistics

- Partner with reliable shipping and logistics companies to ensure prompt and safe delivery to customers.

The production of the Automatic Water Dispenser for Pets demands careful attention to detail and adherence to the outlined procedures. By following this Production Manual, you can ensure consistent quality, functionality, and reliability in the final product. Implementing proper quality control measures will lead to high customer satisfaction and a successful market launch of the Automatic Water Dispenser for Pets.

## 8. References

1. HC-SR04: Datasheet, Specs, and More | ElectroSchematics (https://www.electroschematics.com/hc-sr04-datasheet/)
2. 5V Single-Channel Relay Module - Pin Diagram, Specifications, Applications, Working (components101.com) (https://components101.com/switches/5v-single-channel-relay-module-pinout-features-applications-working-datasheet)
3. https://www.alldatasheet.com/view.jsp?Searchword=ATMEGA328P&sField=4
4. https://curtocircuito.com.br/datasheet/sensor/nivel_de_agua_analogico.pdf

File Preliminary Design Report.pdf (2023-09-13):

## Department of Electronic and Telecommunication Engineering

## University of Moratuwa

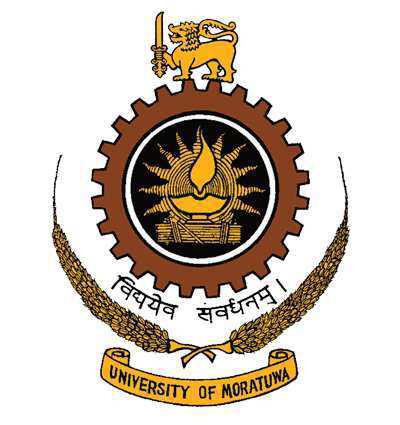
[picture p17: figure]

## EN2160 – Electronic Design Realization

## Preliminary Design Report

## H.M.C.N.K. Bandara

200063X

## 1. Product Description

### 1.1. Need statement

A design which can ensures the continuous supply of clean water for pets

### 1.2. Need Analysis

The design must satisfy following requirements,

- Supply clean water
- Cost effective
- Saves energy
- Supply water continuously

## 2. Implemented original design

### 2.1. Enclosure design

### 2.2. Schematic Design

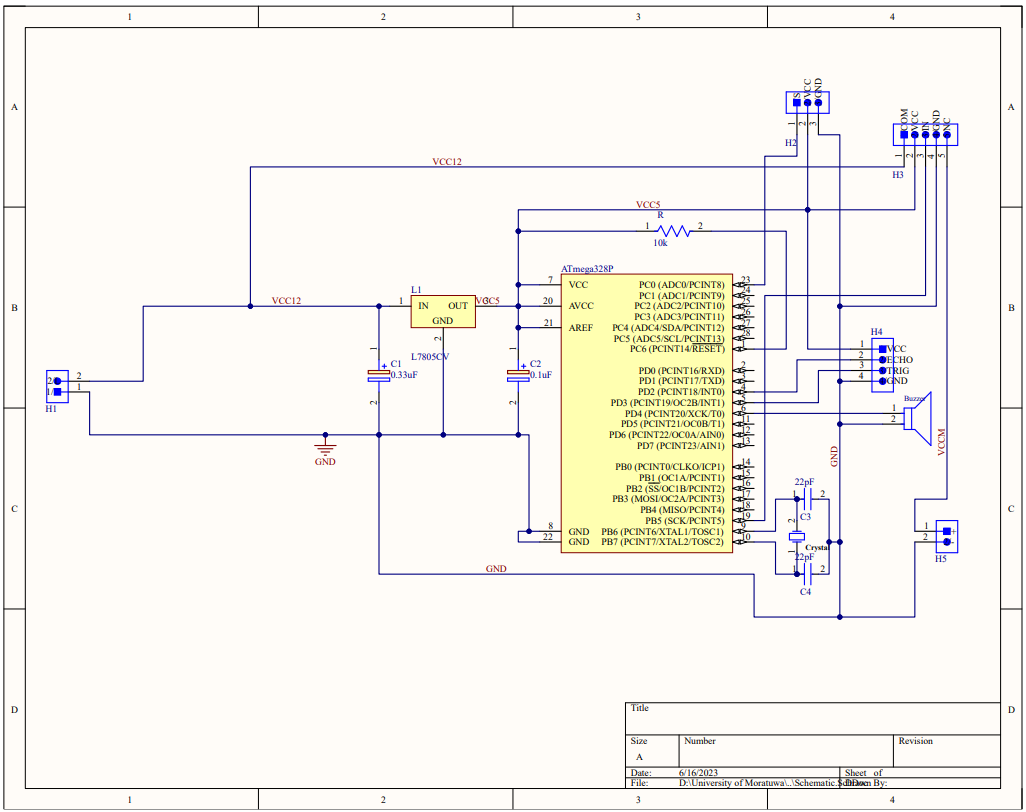
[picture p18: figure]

## 3. Problems identified considering the course content

### 3.1. Schematic design

- The schematic diagram wasn’t suitable for documentation purposes due to following reasons
- The inputs and outputs of the circuits didn’t have a flow from left to right
- The component designators didn’t have consistent numbering

### 3.2. Enclosure design

- The design wasn’t suitable for manufacturing due to following reasons
- It didn’t have draft angles
- It can’t be molded using injection molding
- It had straight edges and pointed vertices
- It wasn’t attractive at all
- The design wasn’t constructed drawing hand sketches first
- The inner enclosure didn’t have proper mounting for some components

## 4. Problems identified by the group members and users

- The ultra-sonic sensor can’t recognize the presence of the pet when it doesn’t come from the front.
- There must be a way to drain the excess water back to the main water container

## 5. Improved Design

### 5.1. Enclosure design

- Curves were added to make the design more aesthetic
- Draft angles were added so that the design is moldable
- Mounting bosses were added to install the PCB and some components
- A sink was added under the top plate to drain the excess water back to the base bucket

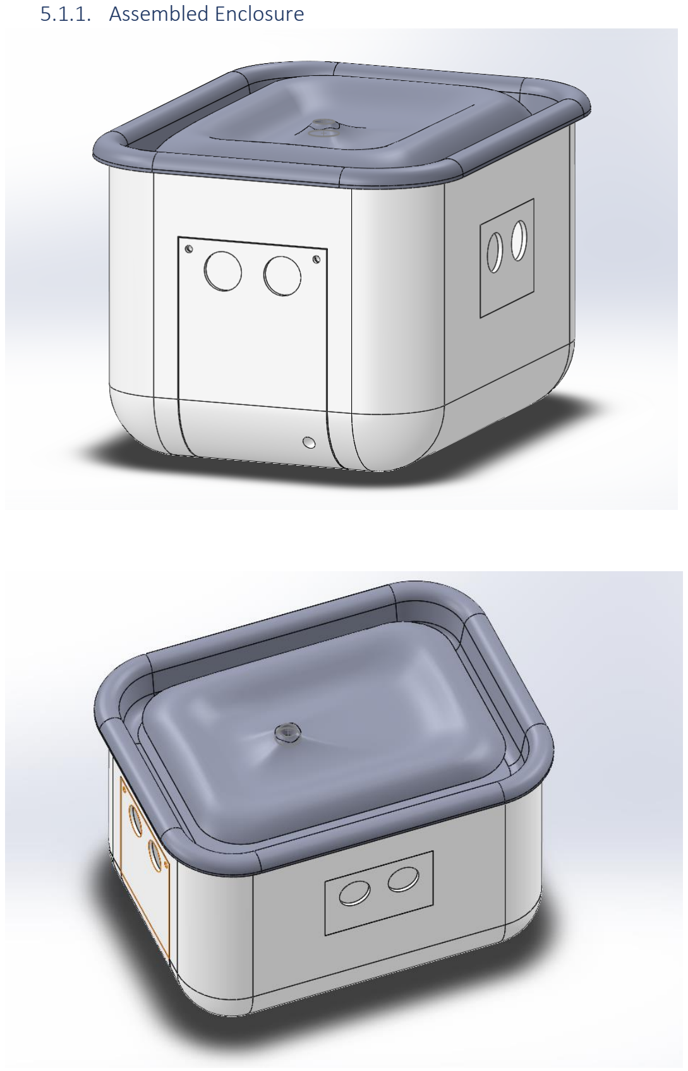
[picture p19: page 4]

5.1.1. Assembled Enclosure

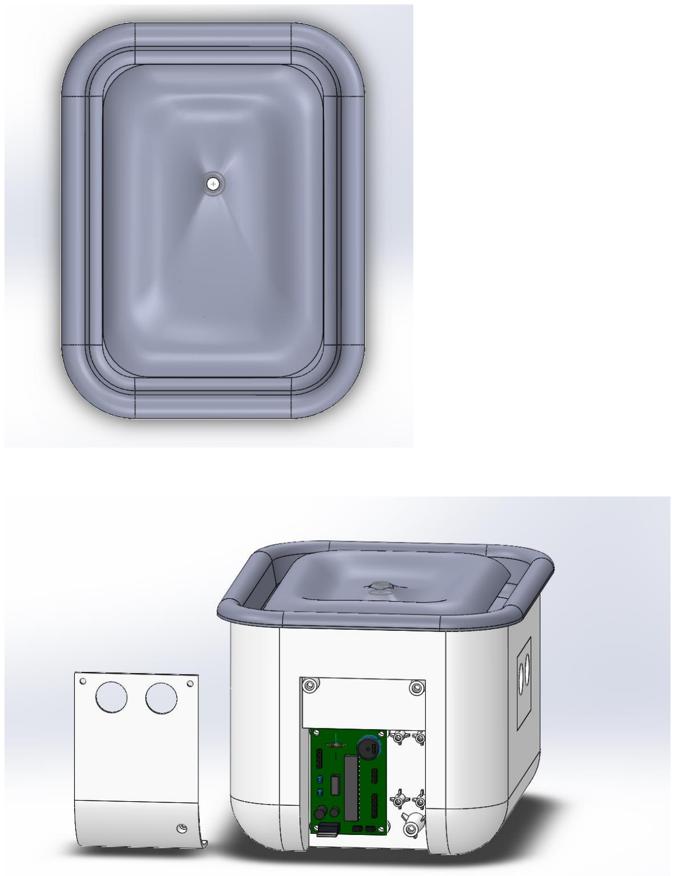
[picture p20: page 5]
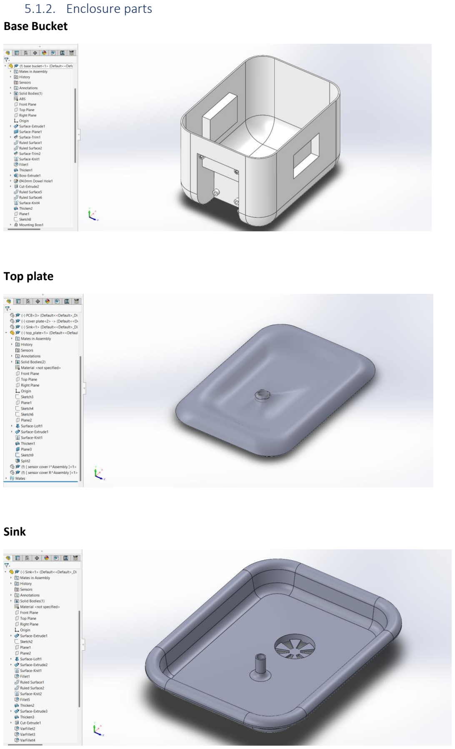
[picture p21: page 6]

5.1.2. Enclosure parts
Base Bucket

Top plate

Sink

### 5.2. Schematic Design

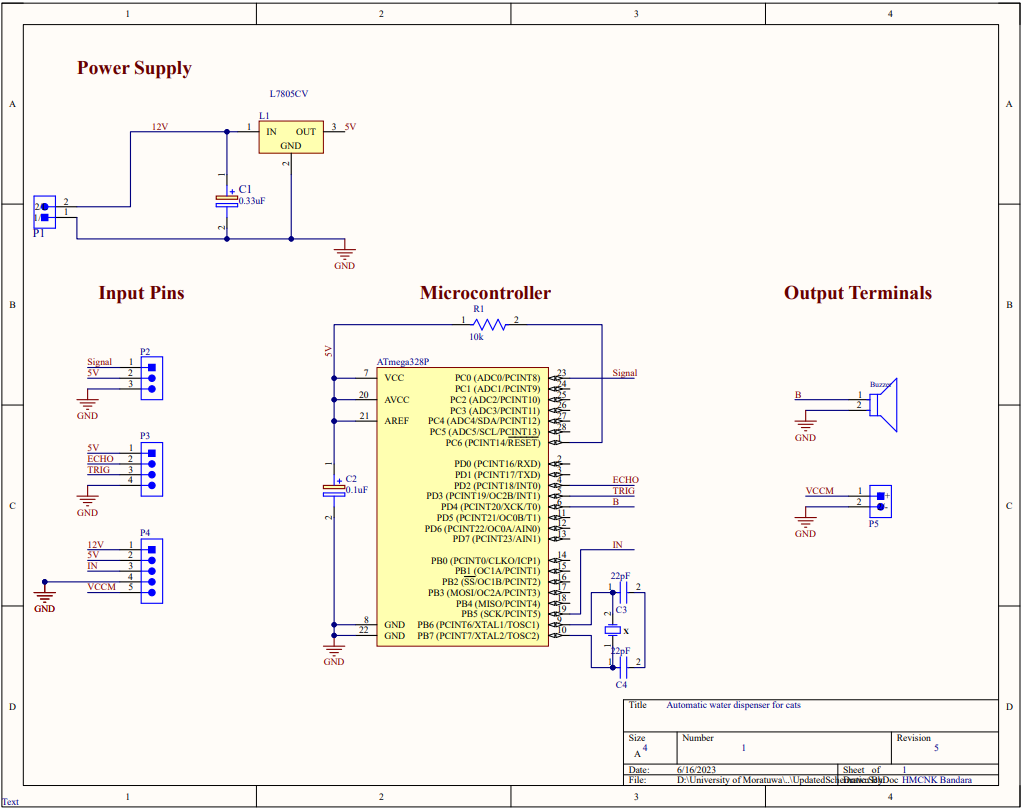
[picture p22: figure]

## 6. Group members who gave their feedbacks on the design

1. 200027R | Amarasinghe A.M.V.M.
2. 200473E | Prabuddhika M.W.R.
3. 200477U | Pramuditha R.M.I.D.
4. 200664P | Tilakarathna U.A.
5. 200222K | Himeka S.H.D.
6. 200287L | Kapukotuwa P.B.K.S.G.
7. 200358G | Luckshan G.W.C.M.

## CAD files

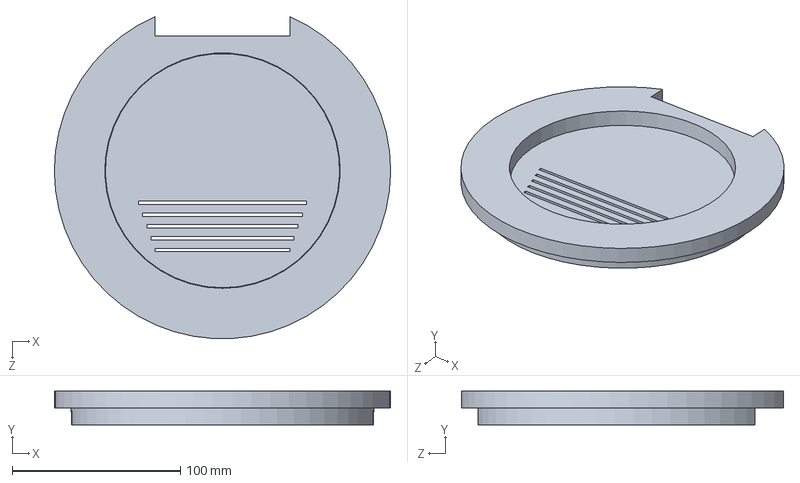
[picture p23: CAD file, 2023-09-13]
Enclosure Design/Parts/Filter Tray.SLDPRT
200.0 x 20.0 x 191.5 mm

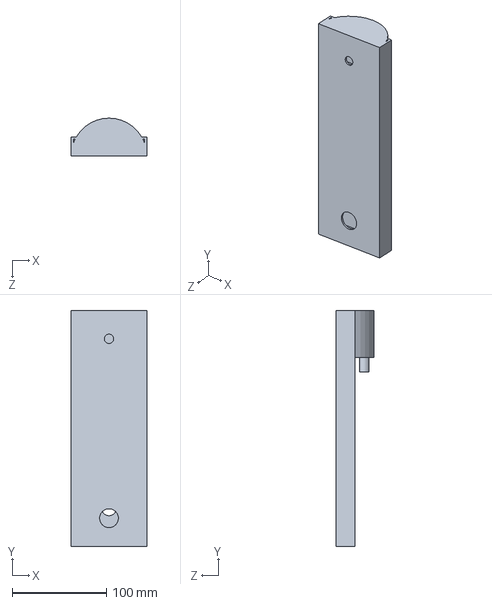
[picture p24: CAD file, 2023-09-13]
Enclosure Design/Parts/Neck.SLDPRT
80.0 x 250.0 x 40.0 mm

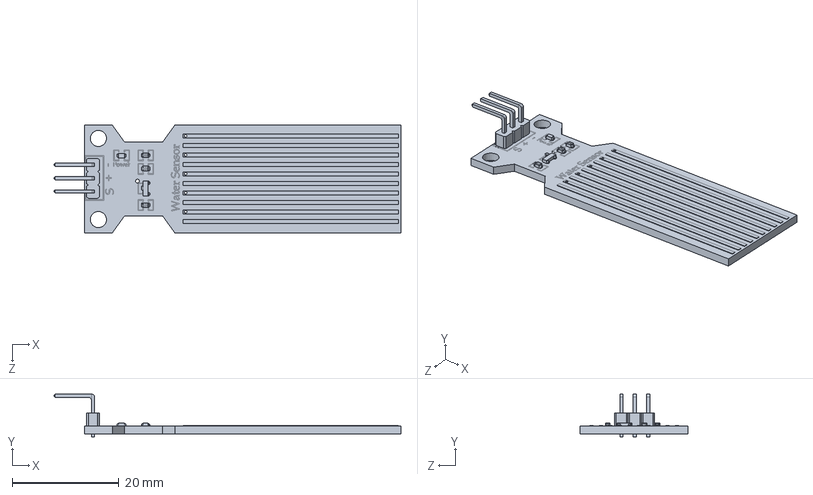
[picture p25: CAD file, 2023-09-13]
Enclosure Design/Parts/Water level sensor.step.SLDPRT
65.0 x 8.00 x 20.2 mm

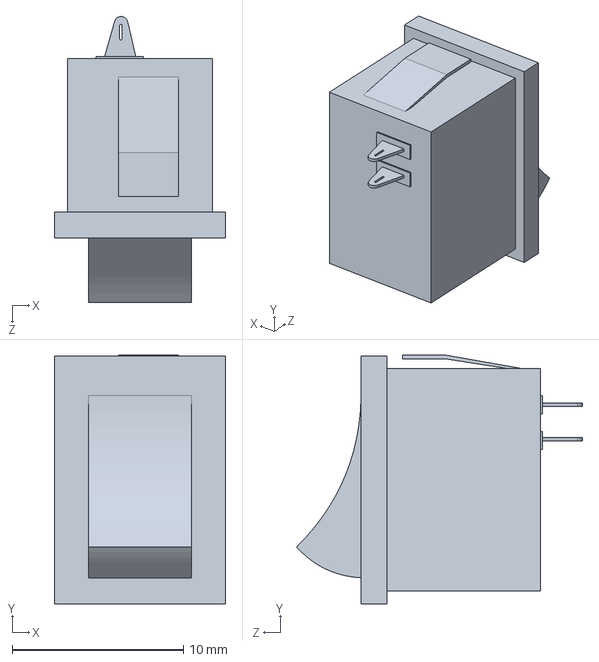
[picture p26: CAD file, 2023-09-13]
Enclosure Design/Parts/ON OFF SWITCH 6A 250V.SLDPRT
10.0 x 14.5 x 16.7 mm

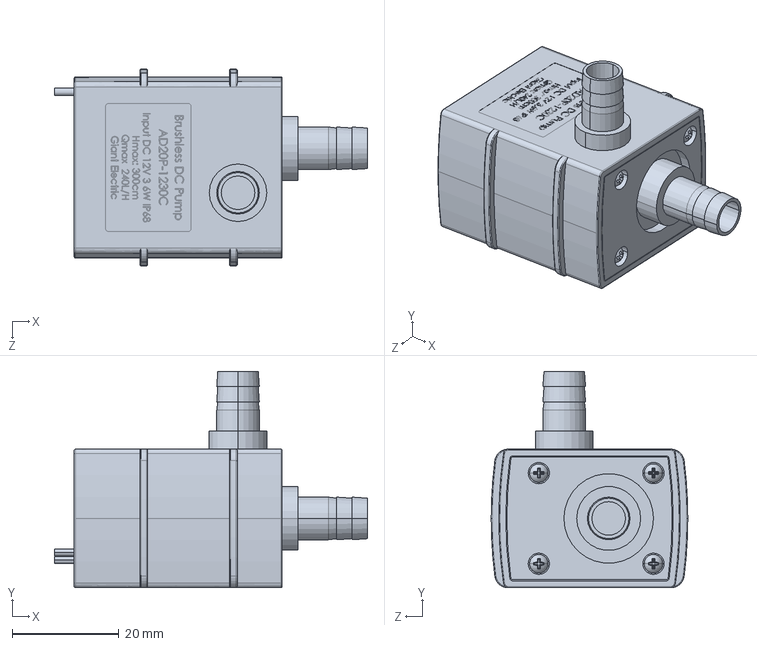
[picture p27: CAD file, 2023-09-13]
Enclosure Design/Parts/Water Pump 12V.SLDPRT
58.7 x 40.6 x 36.9 mm

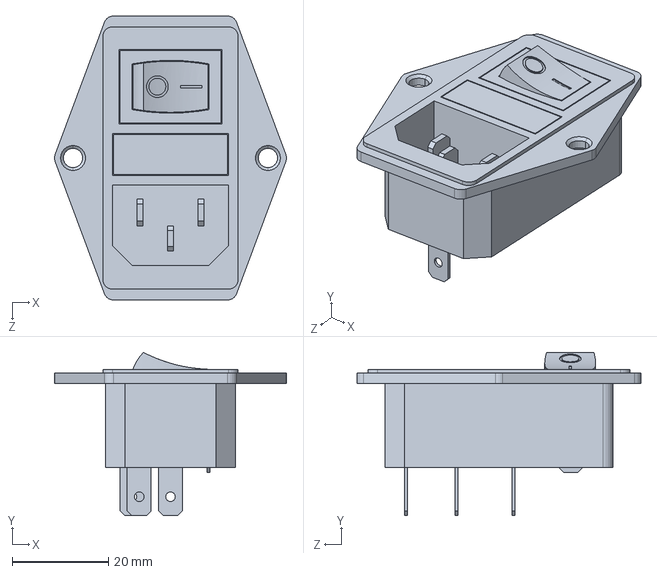
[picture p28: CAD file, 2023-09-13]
Enclosure Design/Parts/Power button with socket.SLDPRT
48.2 x 33.9 x 59.0 mm

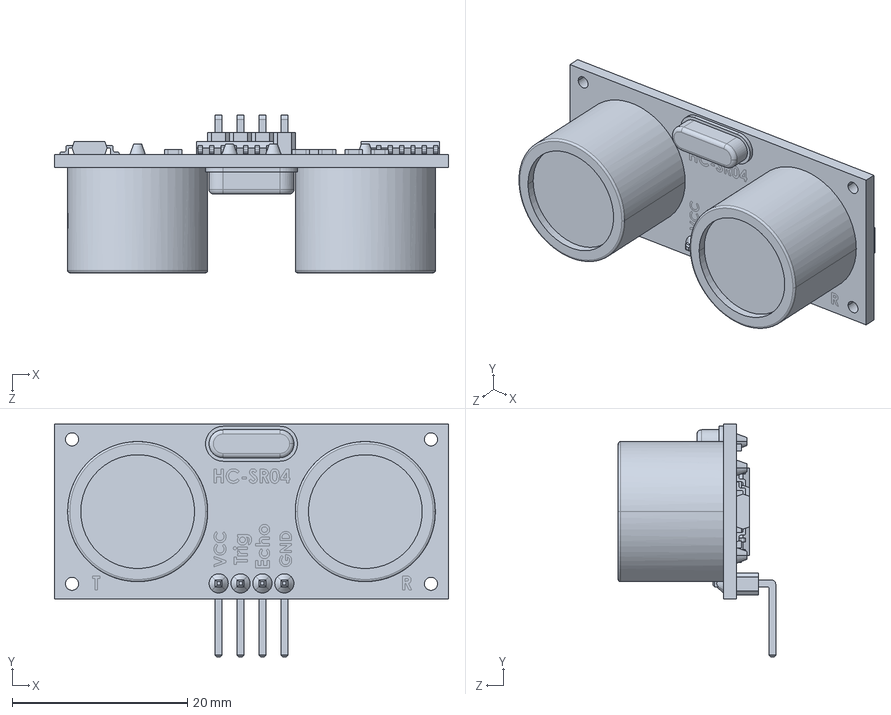
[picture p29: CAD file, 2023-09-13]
Enclosure Design/Parts/HCSR04 Ultrasonic Sensor.step.SLDPRT
45.0 x 26.6 x 18.0 mm

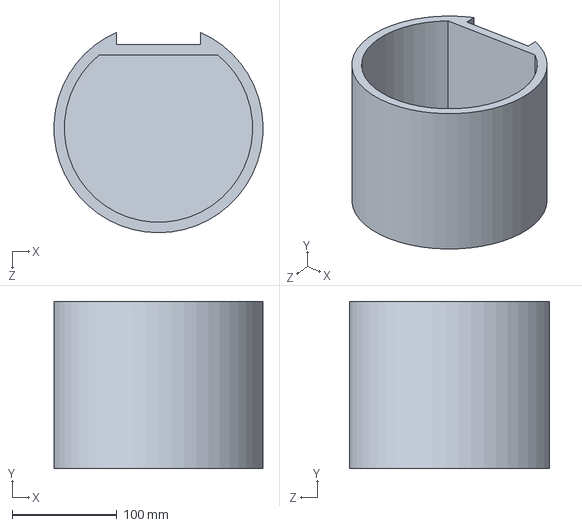
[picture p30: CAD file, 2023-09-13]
Enclosure Design/Parts/water storage_Final.SLDPRT
199.8 x 160.0 x 191.7 mm

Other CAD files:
Enclosure Design/Parts/storage_final.SLDPRT

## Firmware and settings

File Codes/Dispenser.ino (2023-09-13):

/* Change these value according to your calibration value */
int Threshold = 200;

#define sensorPin A0
#define echoPin 2 
#define trigPin 3
#define Control 13
#define Buzzer 4
int val = 0;

long duration; 
int distance; 


void setup()
{
  Serial.begin(9600);
 
  pinMode(trigPin, OUTPUT); 
  pinMode(echoPin, INPUT); 
  pinMode(Control, OUTPUT);
  pinMode(Buzzer,OUTPUT);    
  //digitalWrite(Control, LOW);
  //digitalWrite(Buzzer, LOW);

}

void loop()
{
    
  digitalWrite(trigPin, LOW);
  delayMicroseconds(2);
  digitalWrite(trigPin, HIGH);
  delayMicroseconds(10);
  digitalWrite(trigPin, LOW);
  duration = pulseIn(echoPin, HIGH);
  
  distance = duration * 0.034 / 2;
  Serial.print("Distance: ");
  Serial.print(distance);
  Serial.println(" cm");
  

  int level = analogRead(sensorPin);
  Serial.print("Water level: ");
  Serial.println(level);
  delay(1000);

  if (distance > 30)
  {
   digitalWrite(Control,HIGH);
   Serial.println("Pump Stopped");
   if (level < Threshold)
   {
    digitalWrite(Buzzer,HIGH);
    Serial.println("Buzzer On"); 
   }
   else
   {
    digitalWrite(Buzzer,LOW);
    Serial.println("Buzzer Off");
   }
  }
  else
  {
    if (level < Threshold)
   {
    digitalWrite(Buzzer,HIGH);
    Serial.println("Buzzer On");
    digitalWrite(Control,HIGH);
    Serial.println("Pump Stopped"); 
   }
   else
   {
    digitalWrite(Buzzer,LOW);
    Serial.println("Buzzer Off");
    digitalWrite(Control,LOW);
    Serial.println("Pump Started");
  }
 delay(100);
  }

}

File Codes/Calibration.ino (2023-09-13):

#define sensorPin A0
#define Buzzer 4

int val = 0;
int Threshold = 200;

void setup()
{
  pinMode(Buzzer,OUTPUT);
  Serial.begin(9600);
}

void loop() {

  int level = readSensor();
  
  Serial.print("Water level: ");
  Serial.println(level);
  
  delay(1000);
  if (level < Threshold)
 {
  digitalWrite(Buzzer,HIGH);
  Serial.println("Buzzer On");
 }
 
 else
 {
  digitalWrite(Buzzer,LOW);
  Serial.println("Buzzer Off");
 }
}

  int readSensor() {
 
  val = analogRead(sensorPin);    
  return val;             
}
